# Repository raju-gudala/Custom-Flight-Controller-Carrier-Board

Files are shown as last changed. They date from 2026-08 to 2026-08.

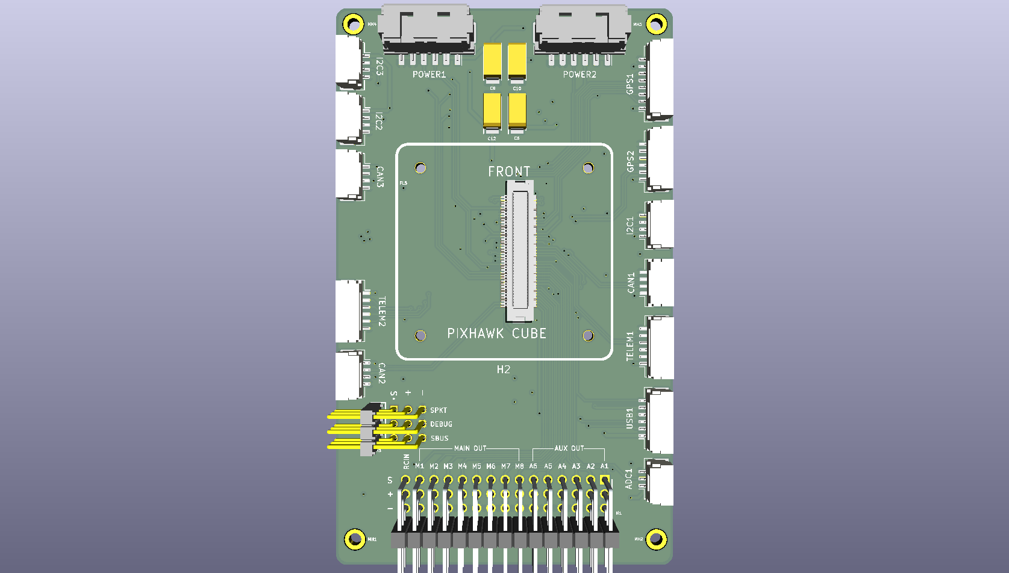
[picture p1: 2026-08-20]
Ti-Circle v1.0_top.png

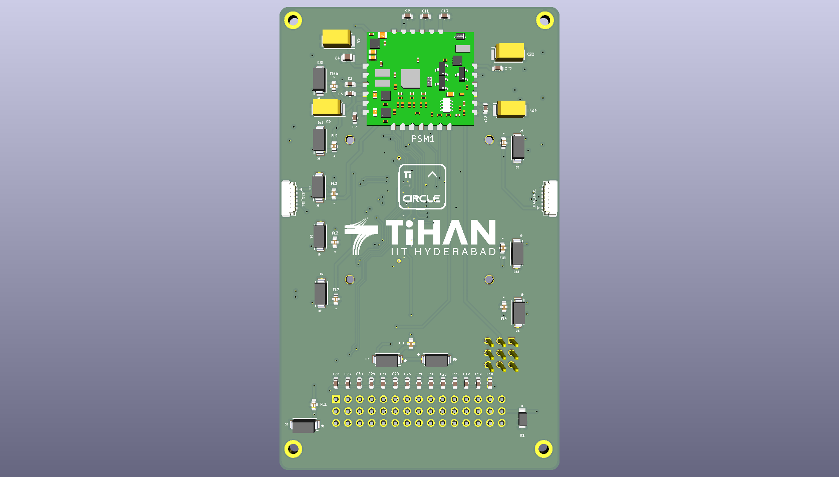
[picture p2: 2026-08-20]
Ti-Circle v1.0_bottom.png

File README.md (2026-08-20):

# Custom Flight Controller Carrier Board

A custom carrier board designed to support the **Pixhawk Cube Orange+** flight controller. The primary objective of this design is to provide a more **ergonomic, organized, and user-friendly interface for port connections**, making it easier to integrate the flight controller with external sensors, peripherals, communication interfaces, and other UAV systems.

The complete hardware design, including schematic capture and PCB layout, was developed using **KiCad**.

## Features

* Custom carrier board designed for **Pixhawk Cube Orange+**
* Ergonomically arranged connectors for easier system integration
* Organized port connections for improved accessibility and wiring
* Custom PCB layout optimized around the Cube Orange+ form factor
* Custom footprints and symbols included for project-specific components
* Complete schematic and PCB design developed in KiCad
* Designed for UAV and flight-control system integration
* Includes PCB visualization images for reference

## Design Overview

The carrier board acts as an interface between the **Pixhawk Cube Orange+** flight controller and external UAV peripherals.

Instead of connecting multiple peripherals directly to the flight controller in a tightly packed arrangement, the carrier board brings the required interfaces to more accessible locations on the PCB. This provides a cleaner wiring arrangement and makes the overall flight-control system easier to assemble, inspect, and maintain.

### Key Design Objectives

* **Ergonomics** — Position commonly used connectors where they are easily accessible.
* **Ease of Integration** — Simplify connections between the Cube Orange+ and external peripherals.
* **Serviceability** — Make wiring, troubleshooting, and maintenance easier.
* **Compact Integration** — Provide a dedicated carrier PCB around the Cube Orange+.
* **Customizability** — Allow the carrier board to be adapted for specific UAV applications.

## Hardware

The board is designed around the **Pixhawk Cube Orange+** flight controller and provides the required physical interface between the flight controller and connected UAV peripherals.

The design includes:

* Cube Orange+ carrier interface
* External peripheral connectors
* Custom connector footprints
* Custom symbols and footprints
* PCB mounting and mechanical interface
* Organized signal and power routing

## Repository Contents

```text
├── Custom Footprints/              # Custom KiCad footprints, symbols and 3D models
├── carrier_board_foot.pretty/      # Project-specific PCB footprints
├── carrier_board_symbols.kicad_sym # Custom schematic symbols
├── fp-lib-table                    # KiCad footprint library configuration
├── Ti-Circle v1.0.kicad_pro        # KiCad project file
├── Ti-Circle v1.0.kicad_sch        # Schematic
├── Ti-Circle v1.0.kicad_pcb        # PCB layout
├── Ti-Circle v1.0_top.png          # Top-side PCB view
├── Ti-Circle v1.0_bottom.png       # Bottom-side PCB view
└── README.md
```

## PCB Layout

The PCB layout was developed with emphasis on:

* Ergonomic connector placement
* Accessible peripheral interfaces
* Clean signal routing
* Practical component placement
* Mechanical compatibility with the Cube Orange+
* Maintainable wiring and system integration

The top and bottom PCB renders are included in the repository for quick visual reference.

## Design Workflow

The complete design was developed using **KiCad**, covering the complete PCB design workflow:

```text
Design Requirements
       ↓
Schematic Design
       ↓
Component & Library Selection
       ↓
PCB Placement
       ↓
PCB Routing
       ↓
Design Verification
       ↓
3D / Layout Review
       ↓
Manufacturing Files
```

## Tools Used

* **KiCad** — Schematic capture, PCB layout, library management, and design verification

## Project Status

**Status:** Custom carrier board design completed.

The repository contains the KiCad schematic, PCB layout, custom libraries, footprints, and reference PCB images required to continue development or review the design.

## License

This project is currently provided for reference and development purposes. If you intend to reuse, modify, or distribute the design, please specify an appropriate open-source hardware license.

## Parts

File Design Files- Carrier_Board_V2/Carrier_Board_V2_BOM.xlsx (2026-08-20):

ID | Designator | Description | Footprint | QTY | MPN | Manufacturer | Link
1 | CAN1, CAN2, CAN3, I2C1, I2C2, I2C3 | CONN HEADER SMD R/A 4POS 1.25MM | JST_GH_SM04B-GHS-TB_1x04-1MP_P1.25mm_Horizontal | 6 | SM04B-GHS-TB(LF)(SN) | JST | https://www.digikey.in/short/2bnhhwwm
2 | GPS1 | CONN HEADER SMD R/A 8POS 1.25MM | JST_GH_SM08B-GHS-TB_1x08-1MP_P1.25mm_Horizontal | 1 | SM08B-GHS-TB(LF)(SN) | JST | https://www.digikey.in/short/vfqqwj5t
3 | POWER1, POWER2 | CONN RCPT 6POS 0.079 TIN SMD R/A | Molex_CLIK-Mate_502494-0670_1x06-1MP_P2.00mm_Horizontal | 2 | 502494-0670 | Molex | https://www.digikey.in/short/5847fjqz
4 | TELEM1, TELEM2, USB1, GPS2 | CONN HEADER SMD R/A 6POS 1.25MM | JST_GH_SM06B-GHS-TB_1x06-1MP_P1.25mm_Horizontal | 4 | SM06B-GHS-TB(LF)(SN) | JST | https://www.digikey.in/short/h0jjd5b4
5 | ADC1 | CONN HEADER SMD R/A 3POS 1.25MM | JST_GH_SM03B-GHS-TB_1x03-1MP_P1.25mm_Horizontal | 1 | SM03B-GHS-TB(LF)(SN) | JST | https://www.digikey.in/short/05m0c499
6 | H2 | CONN HDR 80POS SMD GOLD | PIXHAWK CUBE ORANGE | 1 | DF17(1.0H)-80DP-0.5V(57) | Hirose Electric Co Ltd | https://www.digikey.in/short/19b27vj8
7 | H3 | Connector Header Through Hole, Right Angle 9 position 0.100" (2.54mm) | SAMTEC_HTSW-103-09-G-T-RA | 1 | HTSW-103-09-G-T-RA | SAMTEC | https://mou.sr/4mTSsxR
8 | H1 | Connector Header Through Hole, Right Angle 45 position 0.100" (2.54mm) | HDRRA45W64P254_3X15_3810X254X810P | 1 | TSW-115-08-G-T-RA | SAMTEC | https://mou.sr/428nbxP
9 | PSM1 | Hex / Proficnc Cubepilot Power Selection Module (HX4-06006) | PSM | 1 | Power Selection Module | Hex / Proficnc | https://spexdrone.com/products/hex-proficnc-cubepilot-power-selection-module-hx4-06006 | https://www.dronivo.de/Hex-ProfiCNC-Power-Selection-Module-Pixhawk-21 | https://tienda.stockrc.com/proficnc-PSM-Power-Selection-Module
10 | D2, D3, D4, D5, D6, D7, D8, D9, D10, D11,D12 | TVS DIODE 5VWM 9.2VC DO214AC | DIOM5026X229N | 11 | SMAJ5.0A | Littelfuse | https://www.digikey.in/short/qnrjff33
11 | FL1, FL2, FL3, FL4, FL5, FL6, FL7, FL8, FL9, FL10 | 0.1 µF Feed Through Capacitor 16V 2 A 30mOhm 0603 (1608 Metric), 3 PC Pad | NFM18PC104R1C3D_MUR (0603 LC EMI FILTER) | 10 | NFM18PC104R1C3D | Murata | https://www.digikey.in/short/p2q9t7fq
12 | C3, C7, C9,C11, C13, C14, C15, C16, C17, C18, C19, C20, C21, C24, C25, C26, C27, C28, C29, C30, C31 | CAP CER 0.1UF 50V X7R 0603 | C_0603_1608Metric | 21 | CC0603KRX7R9BB104 | YAGEO | https://www.digikey.in/short/bjwjztn0
13 | D1 | ESD Protection Diodes / TVS Diodes 200W 3.3V 5% Uni-directiona | SMFA2005CA | 1 | SMF3.3 | Littelfuse | https://mou.sr/4tpn2BL
14 | C1 | CAP CER 0.47UF 25V X7R 0603 | C0603 | 1 | CL10B474KA8NNNC | SAMSUNG | https://www.digikey.in/short/c3rf5t3m
15 | C2, C5, C6, C8, C10, C12, C22, C23 | CAP TANT 10UF 10% 35V 2312 | CASE-C_6032 | 8 | TAJC106K035RNJ | Kyocera AVX | https://www.digikey.in/short/c87pbjh7
16 | C4 | Multilayer Ceramic Capacitors MLCC - SMD/SMT 6.3V 1uF X7R 0805 10% | C0805 | 1 | C0805C105K9RACTU | KEMET | https://mou.sr/3P2LSsm
17 | JTAG_FMU1, JTAG_IO1 | CONN HEADER SMD R/A 6POS 0.8MM | JST_SUR_SM06B-SURS-TF_1x06-1MP_P0.80mm_Horizontal | 2 | SM06B-SURS-TF(LF)(SN) | JST | https://www.digikey.in/short/2475bj07

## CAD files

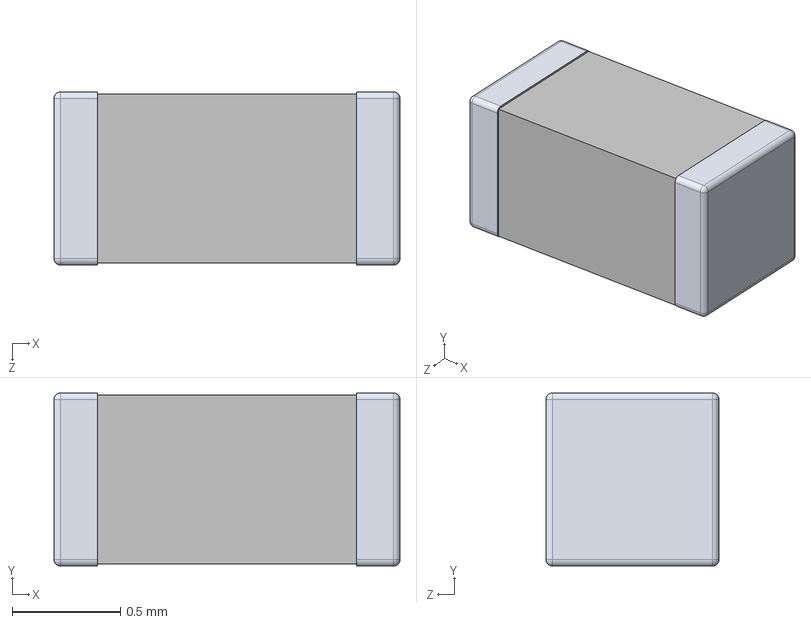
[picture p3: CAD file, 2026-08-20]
Custom Footprints/CC0603KRX7R9BB104/CC0603KRX7R9BB104.stp
1.60 x 0.8 x 0.8 mm

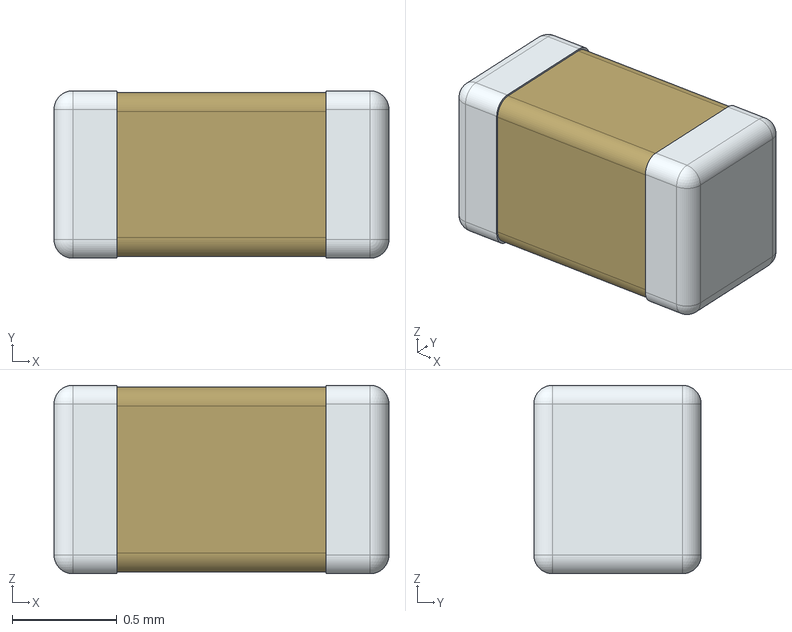
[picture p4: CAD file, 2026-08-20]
Custom Footprints/CL10B474KA8NNNC/CL10B474KA8NNNC.stp
1.60 x 0.8 x 0.9 mm

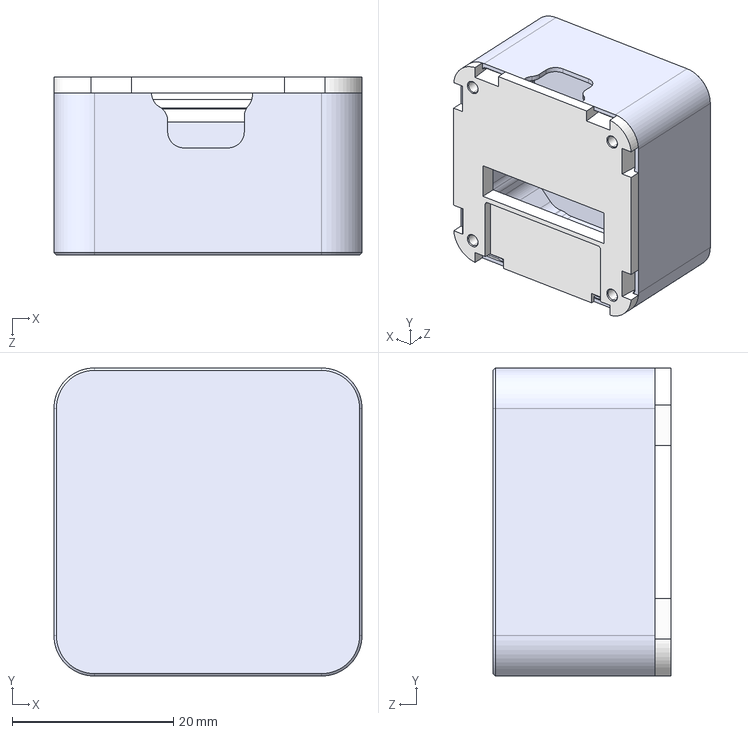
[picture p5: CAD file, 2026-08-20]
Custom Footprints/Cube.STEP/Cube.STEP
38.2 x 38.2 x 22.1 mm
cubemini_base_v1_20180513.stp
std_cube_lid_h20-1mm_20180816.stp

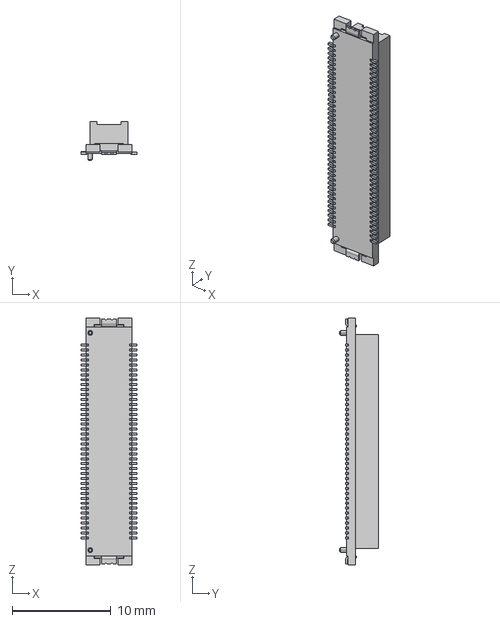
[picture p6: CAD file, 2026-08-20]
Custom Footprints/DF17(1.0H)-80DP-0.5V(57).STEP
5.70 x 3.90 x 25.0 mm

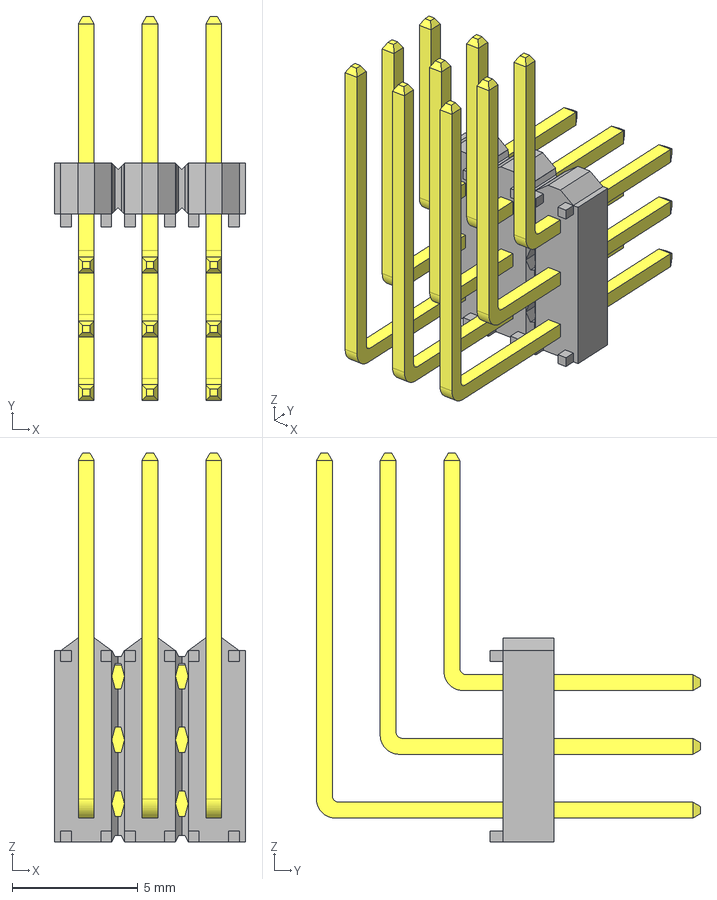
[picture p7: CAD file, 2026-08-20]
Custom Footprints/HTSW-103-09-G-T-RA/HTSW-103-09-G-T-RA.stp
7.62 x 15.3 x 15.5 mm
HTSW-103-09-G-T-RA_body
T-1S6-09-HTSW-1--09-3--G-RA-T
T-1S6-09-HTSW-1--09-3--G-RA-T2

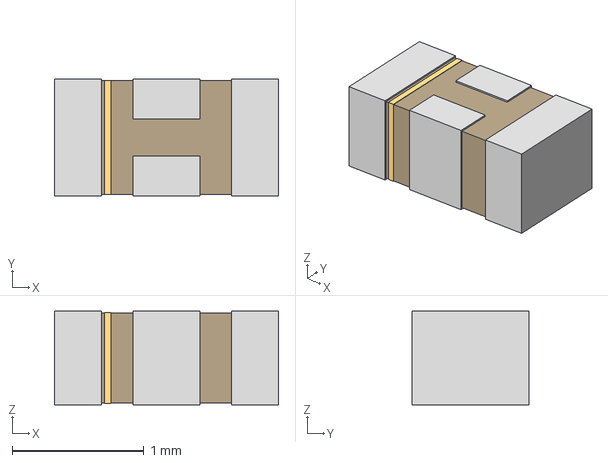
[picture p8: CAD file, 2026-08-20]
Custom Footprints/NFM18PC104R1C3D/NFM18PC104R1C3D_MUR.step
1.70 x 0.888 x 0.711 mm

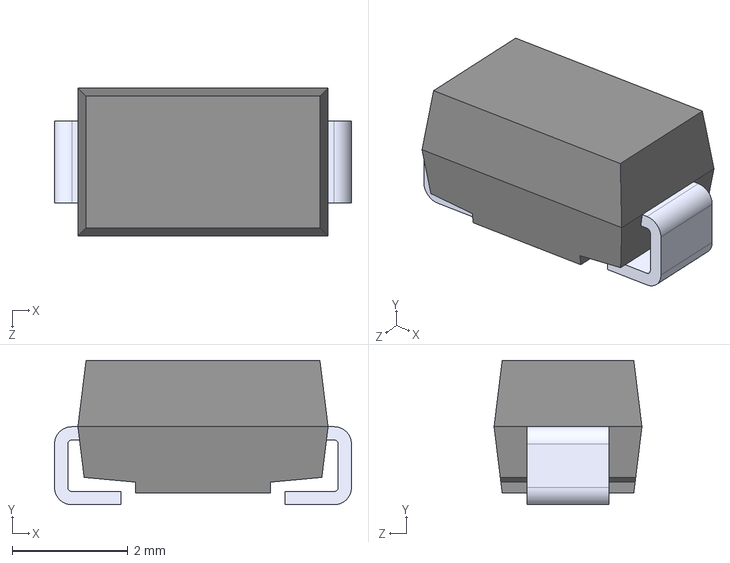
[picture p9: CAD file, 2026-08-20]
Custom Footprints/SMAJ5.0A/SMAJ5.0A.step
5.14 x 2.50 x 2.56 mm

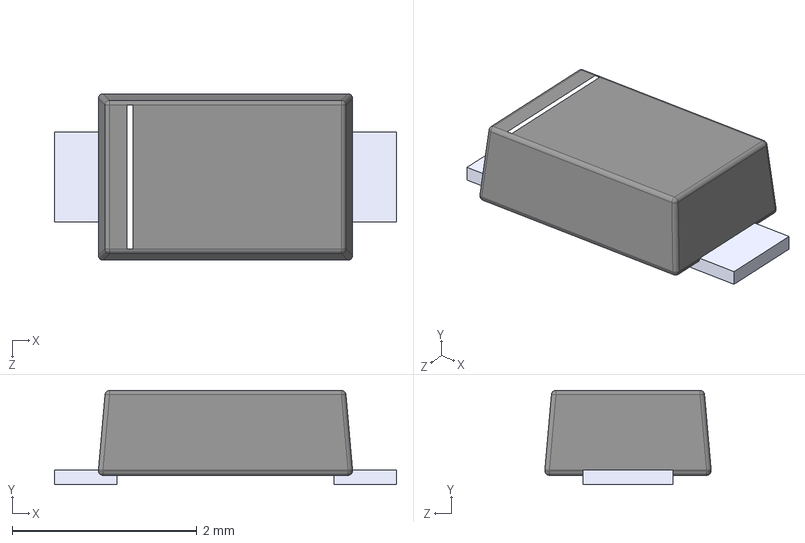
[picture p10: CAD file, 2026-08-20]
Custom Footprints/SMF3.3/SMF3.3.stp
3.70 x 1.02 x 1.80 mm
SMF4L75AH_1
SMF4L75AH_2
SMF4L75AH
SMF4L75AH_3

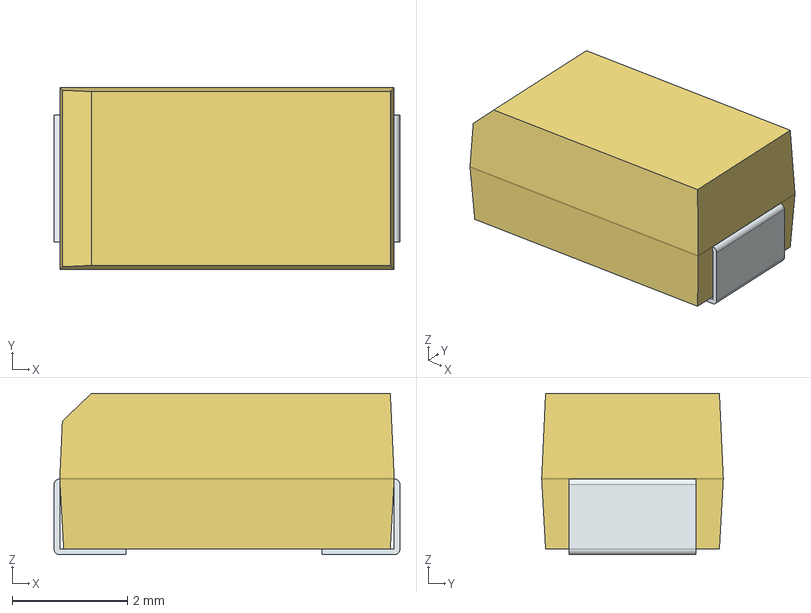
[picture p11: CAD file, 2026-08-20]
Custom Footprints/TAJC106K035RNJ/TAJC106K035RNJ.stp
6.00 x 3.15 x 2.80 mm
FilletPin1
FilletPin2

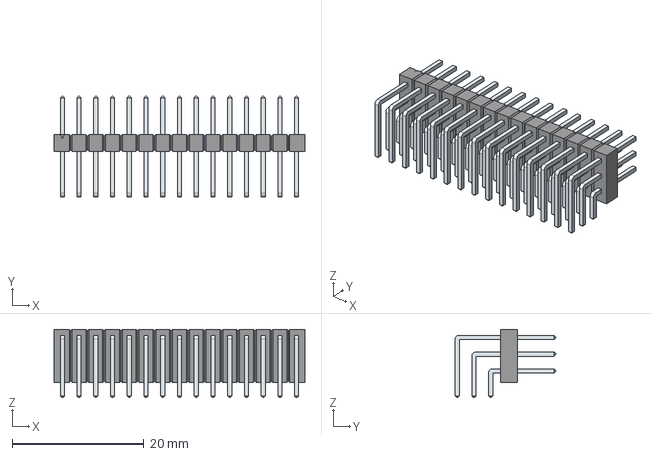
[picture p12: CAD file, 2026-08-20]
Custom Footprints/TSW-115-08-G-T-RA/TSW-115-08-G-T-RA.stp
38.1 x 15.3 x 10.4 mm
LeadsArray x 3

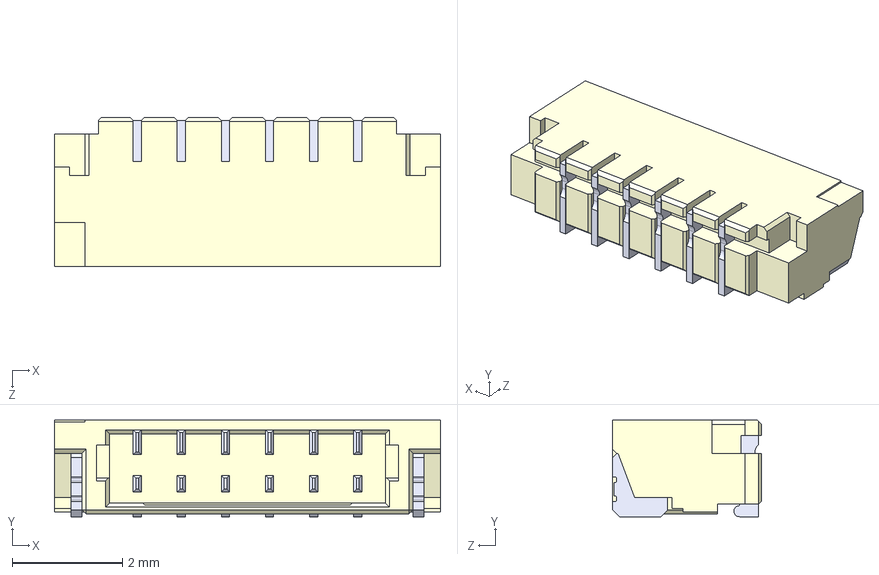
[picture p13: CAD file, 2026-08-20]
Custom Footprints/SM06B-SURS-TF(LF)(SN)--3DModel-STEP-510211.STEP
7.00 x 1.75 x 2.70 mm

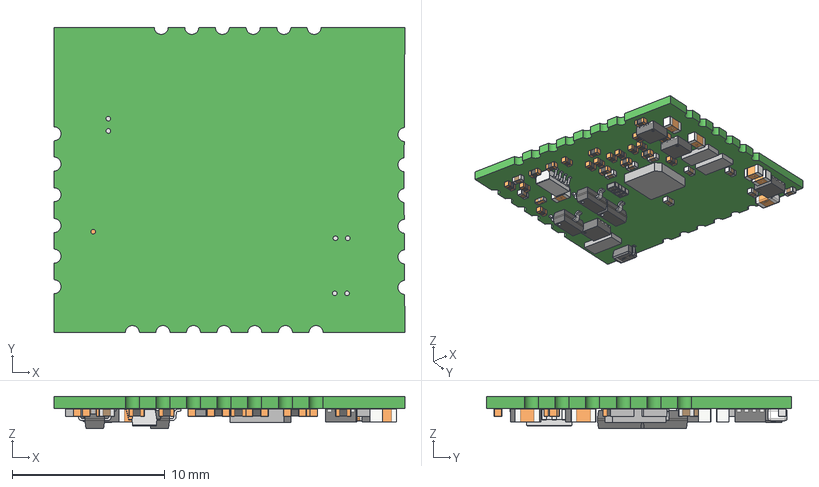
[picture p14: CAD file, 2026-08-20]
Custom Footprints/PSM.step
23.0 x 20.0 x 2.12 mm
Board
MLF-8 x 4
res_0402 x 21
Extruded x 4
User_Library-SOT23-3 x 3
User_Library-SOD323
cap_0402 x 10
cap_0603 x 5
User_Library-SOT23-8
cap_0805
KYOCERA-KNH16-DA
0402(1005M)_Res x 4

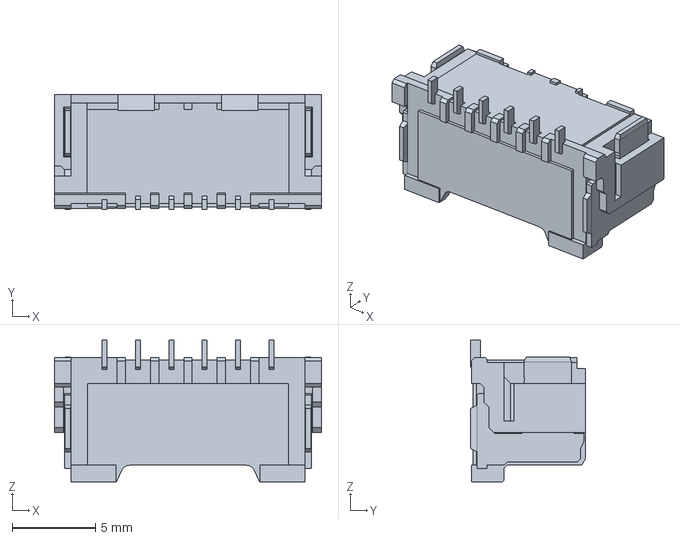
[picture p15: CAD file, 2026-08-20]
Custom Footprints/Molex - 502494-0670/502494-0670.stp
16.0 x 6.90 x 8.50 mm

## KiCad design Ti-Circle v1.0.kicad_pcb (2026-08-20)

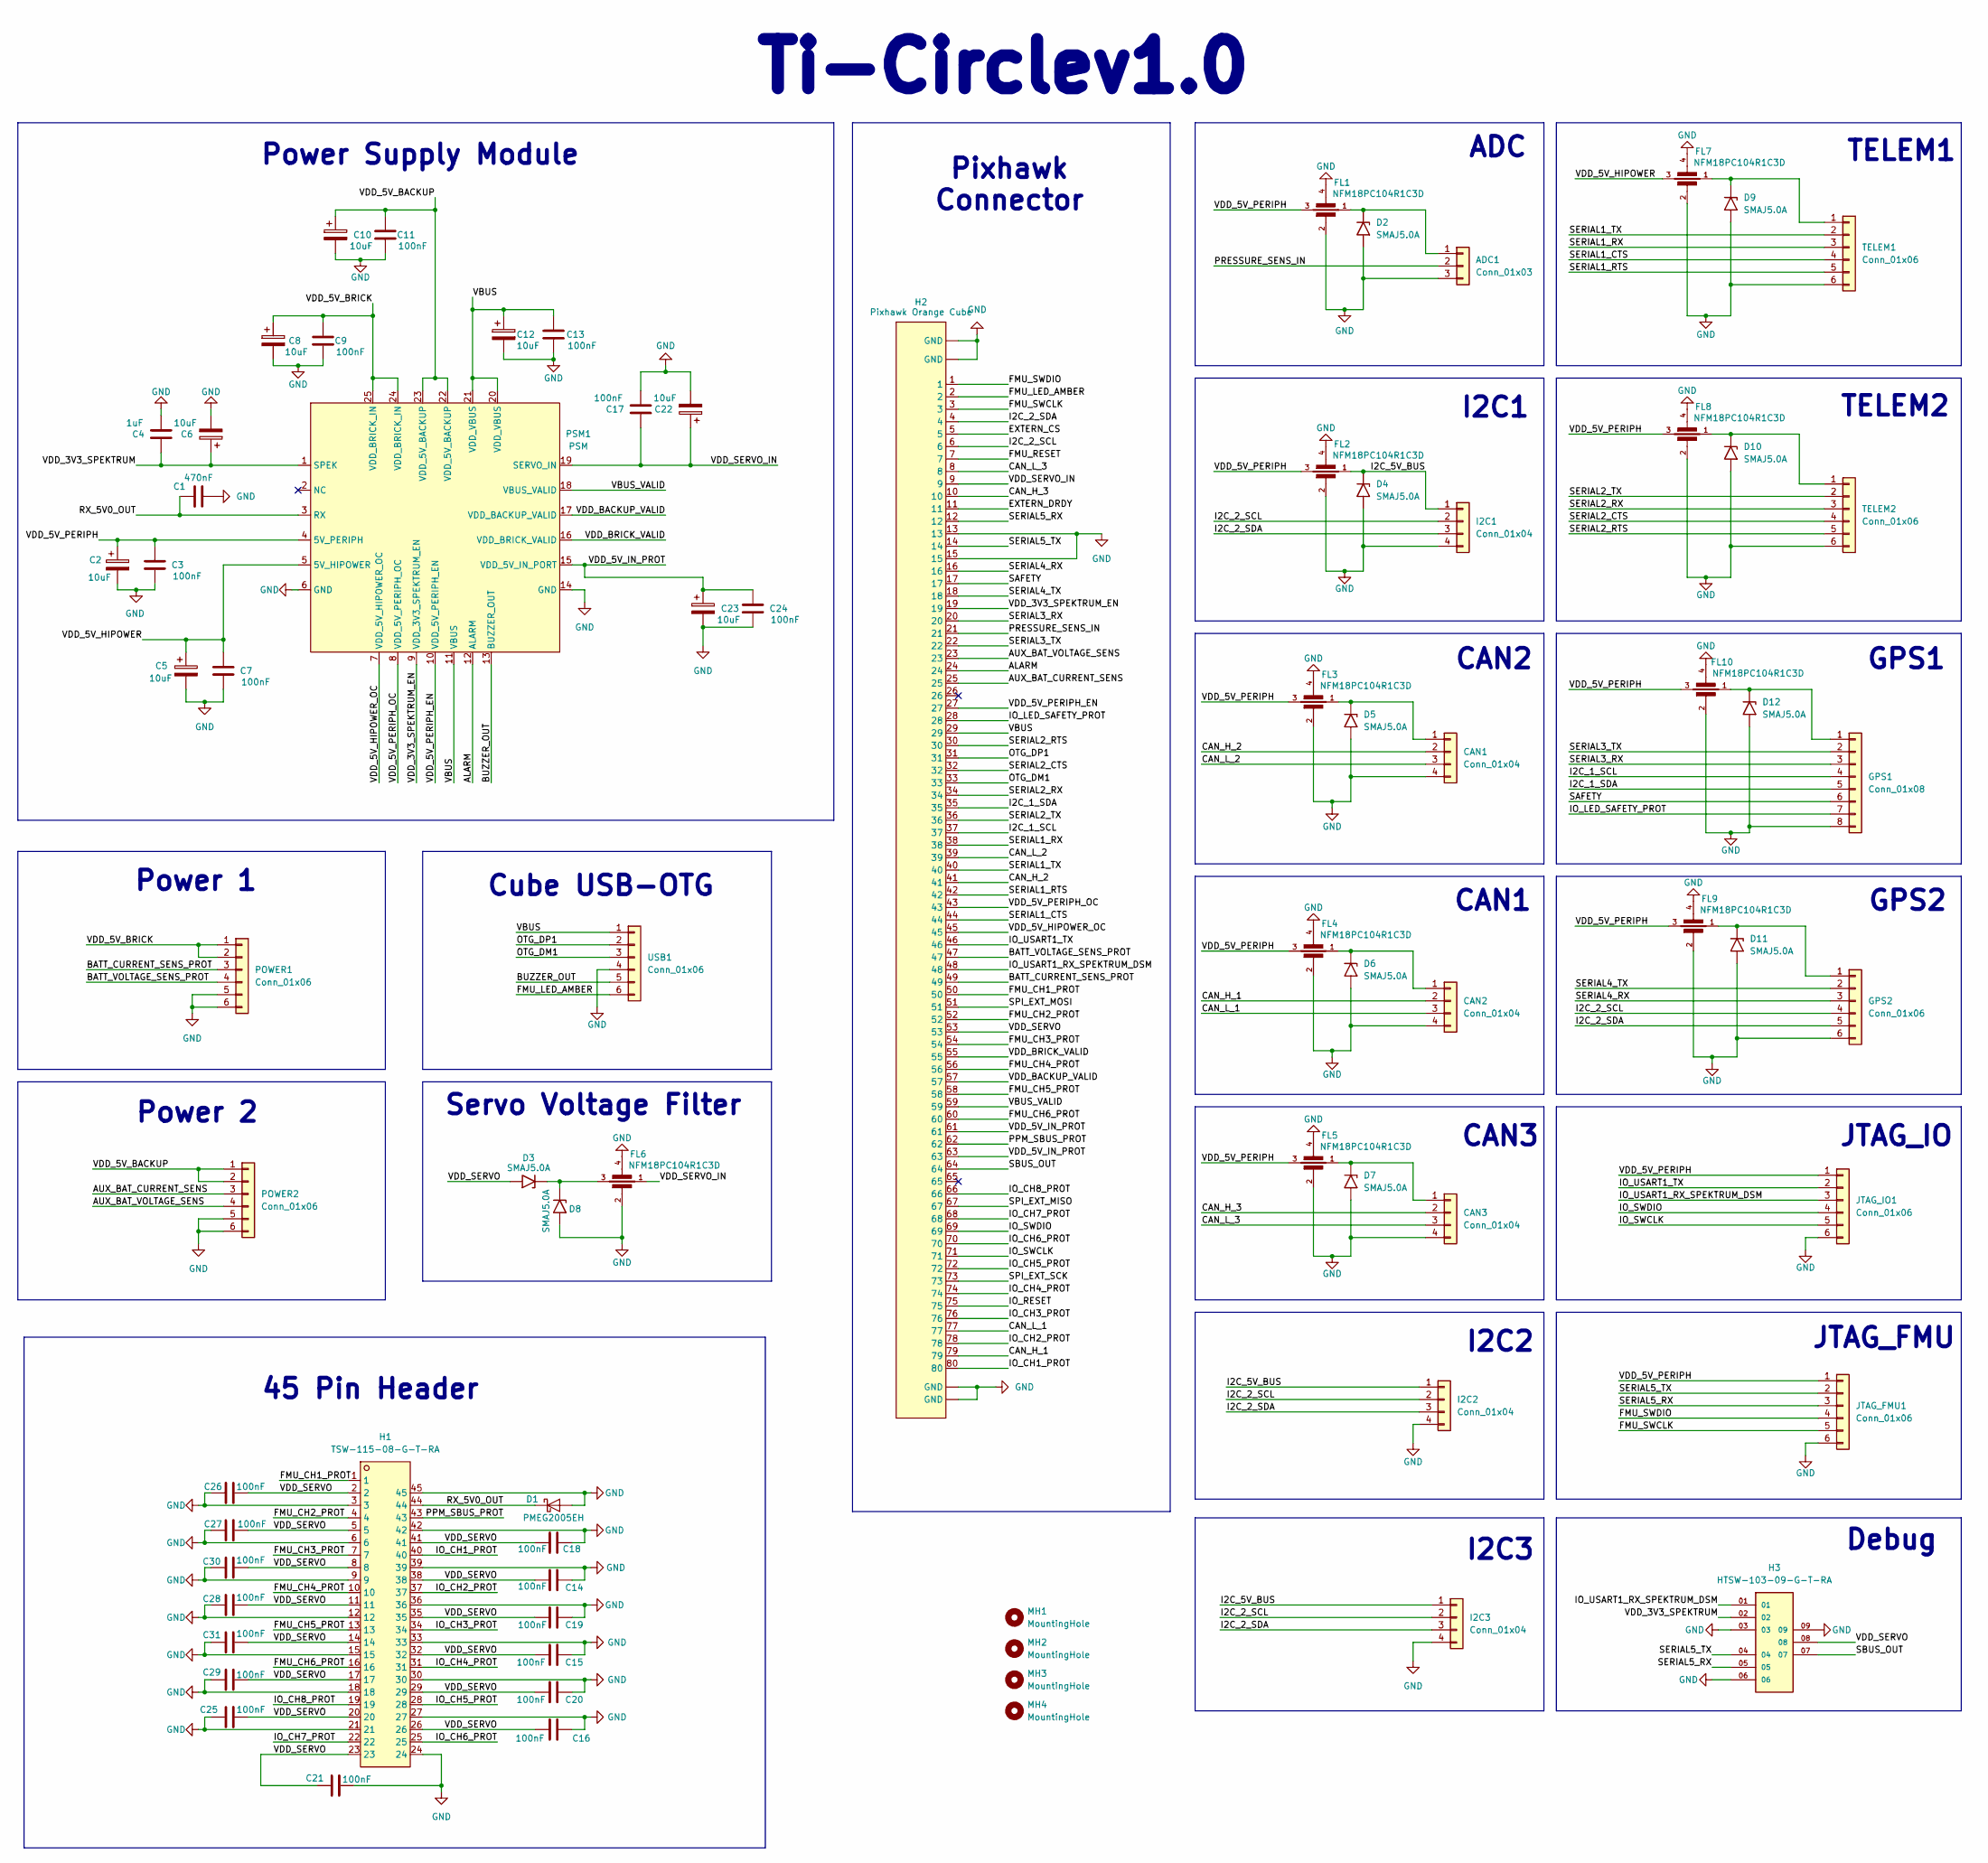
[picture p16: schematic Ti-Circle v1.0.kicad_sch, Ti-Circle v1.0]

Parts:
ADC1: Conn_01x03; JST_GH_SM03B-GHS-TB_1x03-1MP_P1.25mm_Horizontal
C1: 470nF; C_0603_1608Metric
C2, C5, C6, C8, C10, C12, C22, C23: 10uF; CAPPM6032X280N
C3, C7, C9, C11, C13, C14, C15, C16, C17, C18, C19, C20, C21, C24, C25, C26, C27, C28, C29, C30, C31: 100nF; C_0603_1608Metric
C4: 1uF; C_0805_2012Metric
CAN1, CAN2, CAN3: Conn_01x04; JST_GH_SM04B-GHS-TB_1x04-1MP_P1.25mm_Horizontal
D1: PMEG2005EH; SMFA2005CA
D2, D3, D4, D5, D6, D7, D8, D9, D10, D11, D12: SMAJ5.0A; DIOM5026X229N
FL1, FL2, FL3, FL4, FL5, FL6, FL7, FL8, FL9, FL10: NFM18PC104R1C3D; NFM18PC104R1C3D_MUR
GPS1: Conn_01x08; JST_GH_SM08B-GHS-TB_1x08-1MP_P1.25mm_Horizontal
GPS2: Conn_01x06; JST_GH_SM06B-GHS-TB_1x06-1MP_P1.25mm_Horizontal
H1: TSW-115-08-G-T-RA; HDRRA45W64P254_3X15_3810X254X810P
H2: Pixhawk Orange Cube; PIXHAWK CUBE ORANGE
H3: HTSW-103-09-G-T-RA; SAMTEC_HTSW-103-09-G-T-RA
I2C1, I2C2, I2C3: Conn_01x04; JST_GH_SM04B-GHS-TB_1x04-1MP_P1.25mm_Horizontal
JTAG_FMU1: Conn_01x06; JST_SUR_SM06B-SURS-TF_1x06-1MP_P0.80mm_Horizontal
JTAG_IO1: Conn_01x06; JST_SUR_SM06B-SURS-TF_1x06-1MP_P0.80mm_Horizontal
MH1, MH2, MH3, MH4: MountingHole; MountingHole_2.2mm_M2_DIN965_Pad_TopBottom
POWER1, POWER2: Conn_01x06; Molex_CLIK-Mate_502494-0670_1x06-1MP_P2.00mm_Horizontal
PSM1: PSM
TELEM1, TELEM2: Conn_01x06; JST_GH_SM06B-GHS-TB_1x06-1MP_P1.25mm_Horizontal
USB1: Conn_01x06; JST_GH_SM06B-GHS-TB_1x06-1MP_P1.25mm_Horizontal

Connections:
/ALARM: H2.24, PSM1.12 (ALARM)
/AUX_BAT_CURRENT_SENS: H2.25, POWER2.3
/AUX_BAT_VOLTAGE_SENS: H2.23, POWER2.4
/BATT_CURRENT_SENS_PROT: H2.49, POWER1.3
/BATT_VOLTAGE_SENS_PROT: H2.47, POWER1.4
/BUZZER_OUT: PSM1.13 (BUZZER_OUT), USB1.5
/CAN_H_1: CAN2.2, H2.79
/CAN_H_2: CAN1.2, H2.41
/CAN_H_3: CAN3.2, H2.10
/CAN_L_1: CAN2.3, H2.77
/CAN_L_2: CAN1.3, H2.39
/CAN_L_3: CAN3.3, H2.8
/EXTERN_CS: H2.5
/EXTERN_DRDY: H2.11
/FMU_CH1_PROT: H1.1, H2.50
/FMU_CH2_PROT: H1.4, H2.52
/FMU_CH3_PROT: H1.7, H2.54
/FMU_CH4_PROT: H1.10, H2.56
/FMU_CH5_PROT: H1.13, H2.58
/FMU_CH6_PROT: H1.16, H2.60
/FMU_LED_AMBER: H2.2, USB1.6
/FMU_RESET: H2.7
/FMU_SWCLK: H2.3, JTAG_FMU1.5
/FMU_SWDIO: H2.1, JTAG_FMU1.4
/I2C_1_SCL: GPS1.4, H2.37
/I2C_1_SDA: GPS1.5, H2.35
/I2C_2_SCL: GPS2.4, H2.6, I2C1.2, I2C2.2, I2C3.2
/I2C_2_SDA: GPS2.5, H2.4, I2C1.3, I2C2.3, I2C3.3
/I2C_5V_BUS: D4.1 (A1), FL2.1, I2C1.1, I2C2.1, I2C3.1
/IO_CH1_PROT: H1.40, H2.80
/IO_CH2_PROT: H1.37, H2.78
/IO_CH3_PROT: H1.34, H2.76
/IO_CH4_PROT: H1.31, H2.74
/IO_CH5_PROT: H1.28, H2.72
/IO_CH6_PROT: H1.25, H2.70
/IO_CH7_PROT: H1.22, H2.68
/IO_CH8_PROT: H1.19, H2.66
/IO_LED_SAFETY_PROT: GPS1.7, H2.28
/IO_RESET: H2.75
/IO_SWCLK: H2.71, JTAG_IO1.5
/IO_SWDIO: H2.69, JTAG_IO1.4
/IO_USART1_RX_SPEKTRUM_DSM: H2.48, H3.01, JTAG_IO1.3
/IO_USART1_TX: H2.46, JTAG_IO1.2
/OTG_DM1: H2.33, USB1.3
/OTG_DP1: H2.31, USB1.2
/PPM_SBUS_PROT: H1.43, H2.62
/PRESSURE_SENS_IN: ADC1.2, H2.21
/RX_5V0_OUT: C1.1, D1.1 (K), H1.44, PSM1.3 (RX)
/SAFETY: GPS1.6, H2.17
/SBUS_OUT: H2.64, H3.07
/SERIAL1_CTS: H2.44, TELEM1.4
/SERIAL1_RTS: H2.42, TELEM1.5
/SERIAL1_RX: H2.38, TELEM1.3
/SERIAL1_TX: H2.40, TELEM1.2
/SERIAL2_CTS: H2.32, TELEM2.4
/SERIAL2_RTS: H2.30, TELEM2.5
/SERIAL2_RX: H2.34, TELEM2.3
/SERIAL2_TX: H2.36, TELEM2.2
/SERIAL3_RX: GPS1.3, H2.20
/SERIAL3_TX: GPS1.2, H2.22
/SERIAL4_RX: GPS2.3, H2.16
/SERIAL4_TX: GPS2.2, H2.18
/SERIAL5_RX: H2.12, H3.05, JTAG_FMU1.3
/SERIAL5_TX: H2.14, H3.04, JTAG_FMU1.2
/SPI_EXT_MISO: H2.67
/SPI_EXT_MOSI: H2.51
/SPI_EXT_SCK: H2.73
/VBUS: C12.1, C13.1, H2.29, PSM1.11 (VBUS), PSM1.20 (VDD_VBUS), PSM1.21 (VDD_VBUS), USB1.1
/VBUS_VALID: H2.59, PSM1.18 (VBUS_VALID)
/VDD_3V3_SPEKTRUM: C4.1, C6.1, H3.02, PSM1.1 (SPEK)
/VDD_3V3_SPEKTRUM_EN: H2.19, PSM1.9 (VDD_3V3_SPEKTRUM_EN)
/VDD_5V_BACKUP: C10.1, C11.1, POWER2.1, POWER2.2, PSM1.22 (VDD_5V_BACKUP), PSM1.23 (VDD_5V_BACKUP)
/VDD_5V_BRICK: C8.1, C9.1, POWER1.1, POWER1.2, PSM1.24 (VDD_BRICK_IN), PSM1.25 (VDD_BRICK_IN)
/VDD_5V_HIPOWER: C5.1, C7.1, FL7.3, PSM1.5 (5V_HIPOWER)
/VDD_5V_HIPOWER_OC: H2.45, PSM1.7 (VDD_5V_HIPOWER_OC)
/VDD_5V_IN_PROT: C23.1, C24.1, H2.61, H2.63, PSM1.15 (VDD_5V_IN_PORT)
/VDD_5V_PERIPH: C2.1, C3.1, FL1.3, FL2.3, FL3.3, FL4.3, FL5.3, FL8.3, FL9.3, FL10.3, JTAG_FMU1.1, JTAG_IO1.1, PSM1.4 (5V_PERIPH)
/VDD_5V_PERIPH_EN: H2.27, PSM1.10 (VDD_5V_PERIPH_EN)
/VDD_5V_PERIPH_OC: H2.43, PSM1.8 (VDD_5V_PERIPH_OC)
/VDD_BACKUP_VALID: H2.57, PSM1.17 (VDD_BACKUP_VALID)
/VDD_BRICK_VALID: H2.55, PSM1.16 (VDD_BRICK_VALID)
/VDD_SERVO: C14.2, C15.2, C16.1, C18.2, C19.2, C20.2, C21.1, C25.2, C26.1, C27.1, C28.1, C29.1, C30.1, C31.1, D3.2 (A2), H1.2, H1.5, H1.8, H1.11, H1.14, H1.17, H1.20, H1.23, H1.26, H1.29, H1.32, H1.35, H1.38, H1.41, H2.53, H3.08
/VDD_SERVO_IN: C17.1, C22.1, FL6.1, H2.9, PSM1.19 (SERVO_IN)
GND: ADC1.3, C1.2, C2.2, C3.2, C4.2, C5.2, C6.2, C7.2, C8.2, C9.2, C10.2, C11.2, C12.2, C13.2, C14.1, C15.1, C16.2, C17.2, C18.1, C19.1, C20.1, C21.2, C22.2, C23.2, C24.2, C25.1, C26.2, C27.2, C28.2, C29.2, C30.2, C31.2, CAN1.4, CAN2.4, CAN3.4, D1.2 (A), D2.2 (A2), D4.2 (A2), D5.2 (A2), D6.2 (A2), D7.2 (A2), D8.2 (A2), D9.2 (A2), D10.2 (A2), D11.2 (A2), D12.2 (A2), FL1.2, FL1.4, FL2.2, FL2.4, FL3.2, FL3.4, FL4.2, FL4.4, FL5.2, FL5.4, FL6.2, FL6.4, FL7.2, FL7.4, FL8.2, FL8.4, FL9.2, FL9.4, FL10.2, FL10.4, GPS1.8, GPS2.6, H1.3, H1.6, H1.9, H1.12, H1.15, H1.18, H1.21, H1.24, H1.27, H1.30, H1.33, H1.36, H1.39, H1.42, H1.45, H2. (GND), H2.13, H2.15, H3.03, H3.06, H3.09, I2C1.4, I2C2.4, I2C3.4, JTAG_FMU1.6, JTAG_IO1.6, POWER1.5, POWER1.6, POWER2.5, POWER2.6, PSM1.6 (GND), PSM1.14 (GND), TELEM1.6, TELEM2.6, USB1.4
unnamed: ADC1.1, D2.1 (A1), FL1.1
unnamed: CAN1.1, D5.1 (A1), FL3.1
unnamed: CAN2.1, D6.1 (A1), FL4.1
unnamed: CAN3.1, D7.1 (A1), FL5.1
unnamed: D3.1 (A1), D8.1 (A1), FL6.3
unnamed: D9.1 (A1), FL7.1, TELEM1.1
unnamed: D10.1 (A1), FL8.1, TELEM2.1
unnamed: D11.1 (A1), FL9.1, GPS2.1
unnamed: D12.1 (A1), FL10.1, GPS1.1

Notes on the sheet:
CAN1
Power 1
GPS1
Cube USB-OTG
GPS2
Servo Voltage Filter
ADC
Debug
Pixhawk Connector
CAN3
TELEM1
I2C1
I2C3
Ti-Circlev1.0
Power Supply Module
I2C2
Power 2
JTAG_IO
45 Pin Header
JTAG_FMU
CAN2
TELEM2

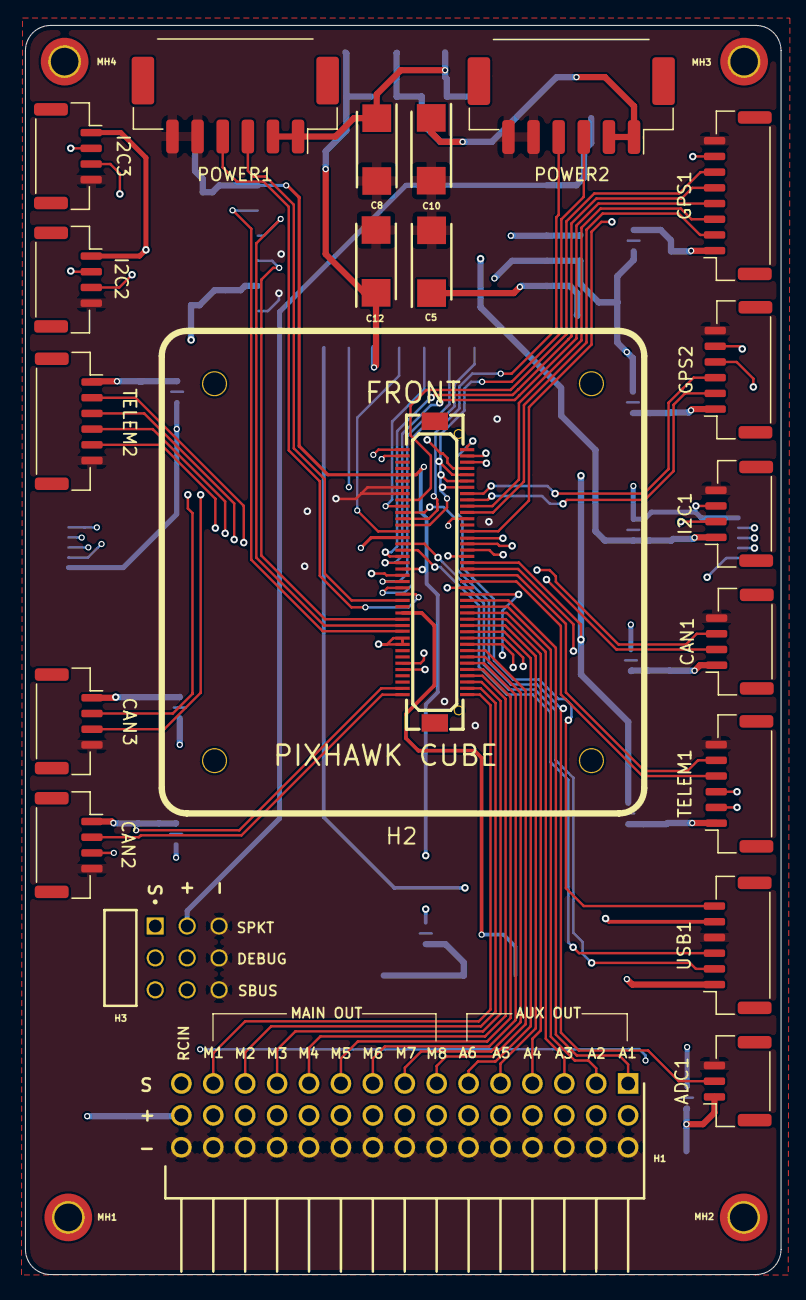
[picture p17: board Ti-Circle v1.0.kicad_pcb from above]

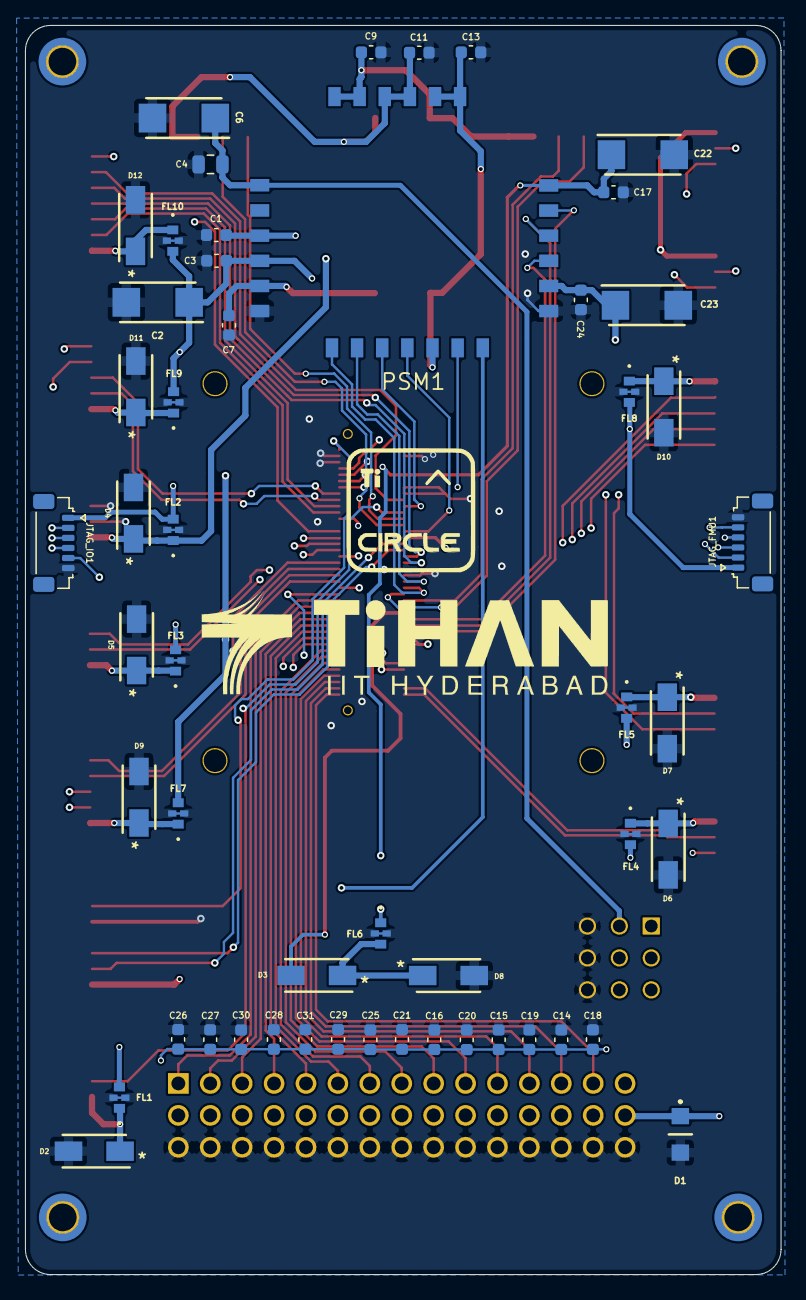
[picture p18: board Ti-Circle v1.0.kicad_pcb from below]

Board: 4 copper layers, 60.1 x 99.4 mm, 77 parts (52 on the bottom side), 86 nets.

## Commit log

2026-08-20 Initial commit - Ti-Circle v1.0
    [502494-0670.stp, 5024940670.stp, CC0603KRX7R9BB104.stp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]
2026-08-20 Update Git ignore rules for KiCad files

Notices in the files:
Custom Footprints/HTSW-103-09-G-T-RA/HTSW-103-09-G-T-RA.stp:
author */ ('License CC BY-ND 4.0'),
